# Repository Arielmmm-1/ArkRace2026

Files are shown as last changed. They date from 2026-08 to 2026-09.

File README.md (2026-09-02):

# Ark_Race2026


2026第五届方舟计划机器人大赛自述留档

## 废话
虽然这东西像破烂,但确实是我想出来的,但只停在想象,没考虑实际就直接做了,吸取教训吧🤫

## 目录结构
- 1.Embedded Team 电控组文件
- 2.Mechanical Group 机械组文件
- 3.培训‑机械组培训内容
- 4.Embedded Team\OLEDtest 整车电控文件，推荐 VSCode 打开
    - 其余为旧版本、临时文件、商家文件
- 5.Mechanical Group\我说元神牛逼你说队‑机械建模文件
    - 其余为26场地文件，参赛手册
      
## 📌 整车基础参数
- 参赛赛事：第五届方舟计划机器人大赛
- 整车重量：5.7kg（含遥控器）

---

## ⚙️ 一、硬件选型问题复盘
### 1. 驱动电机
- 核心问题：未计算整车负载扭矩，电机扭矩余量严重不足
- 实际表现：整车负重后速度疲软、动力不足
- 结构不匹配：该电机轴径小、原生不适配大直径车轮，重载工况非常吃力
- 迭代方案：后续可更换 24V 520 / 550 大扭矩电机，适配重载大轮场景


### 2. 法兰联轴器
- 现状：电机轴仅4mm，市面仅能匹配小型单面法兰联轴器
- 致命缺陷：大麦轮自重+惯性大，仅靠单颗六角螺母锁止完全不够
- 实战问题：全向平移时车轮微震、螺丝松动、运行极易掉轮


### 3. 主控板子（嘉立创天空星 F407VET6）
- 优点：F407芯片资源充足、主频、外设、内存完全满足比赛需求
- 事故问题：调试期间两次开发板烧毁
- 疑似原因：带电插拔、不断电操作导致瞬间电压冲击击穿
- 规范整改：后续所有接线、插拔、改装必须全程断电操作


---

## 🏗️ 二、底盘结构设计缺陷
### 1. 平板式底盘
- 结构短板：纯平面薄板底盘，不适合大尺寸、大重量车体
- 实际问题：整车5.7kg负重后底盘下沉形变，车轮倾角偏移
- 核心痛点：麦轮全向解算极度依赖结构刚性，形变误差软件完全无法补偿
- 经验总结：平板底盘仅适合小型轻量化小车，应该考虑采用铝型材框架的


### 附件可参考设计



---

## 📐 三、升降传送机构重大设计问题
### 1. 单边受力倾覆问题
- 结构硬伤：升降横梁左侧承载负载，产生巨大下压倾覆力矩
- 受力畸形：动力源集中在最右侧，受力点严重不对称
- 最后会出现光轴滑块卡顿、升降不顺、结构偏斜


### 2. 竖直立柱无闭环固定
- 设计漏洞：两根500mm高竖杆顶部无固定框架，未形成刚性矩形闭环
- 运动缺陷：车体一动，立柱整体高频抖动、振幅极大
(设计的时候以为横梁可以稳定这两根杆)

### 3. 步进电机固定方案简陋
- 现状：前期未预留标准安装孔位
- 临时方案：仅靠胶水+扎带固定，刚性极差、极易松动
- 改进：后续结构建模优先预留电机固定座、孔位
  
### 迭代优化思路
- 将传送驱动轴居中布置，右侧改为纯支撑光轴，弱化单边倾覆力
- 单根导向杆改为采用双滑块/四滑块到龙门架的结构，大幅提升承载稳定性


### 附件可参考设计



---

## 🤌 四、末端夹取机构总结
- 现状：舵机夹爪为赛前一晚才买的配件
- 优点：常规抓取表现尚可，适配比赛基础需求
- 缺陷：夹爪行程不足，无法包覆半个球体，抓取容错率低
- 后续升级方向：气动夹爪 / 磁吸抓取结构，稳定性、负载能力全面升级
  

### 附件


1f232b22a2a29387cc7f6337f348d309

---

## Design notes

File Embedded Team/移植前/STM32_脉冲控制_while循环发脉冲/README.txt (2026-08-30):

/**********************************************************
***	Emm_V5.0步进闭环控制例程
***	控制例程：STM32_脉冲控制_while循环发送脉冲
***	编写作者：ZHANGDATOU
***	技术支持：张大头闭环伺服
***	淘宝店铺：https://zhangdatou.taobao.com
***	CSDN博客：http s://blog.csdn.net/zhangdatou666
***	qq交流群：262438510
**********************************************************/

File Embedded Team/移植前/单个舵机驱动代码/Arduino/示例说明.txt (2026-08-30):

ResetServo	上电自动复位
Servo		循环让舵机从 0 度到 180 度，每隔 10 度转一次
MoreServo   多舵机控制

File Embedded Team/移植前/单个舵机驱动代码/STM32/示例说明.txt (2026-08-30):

01-Servo	上电自动复位
02-PulseServo	脉冲控制
03-AngleServo	通过角度控制

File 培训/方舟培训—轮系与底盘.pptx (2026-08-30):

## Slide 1

机器人常见轮系与底盘设计

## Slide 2

麦克纳姆轮

3

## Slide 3

麦轮结构

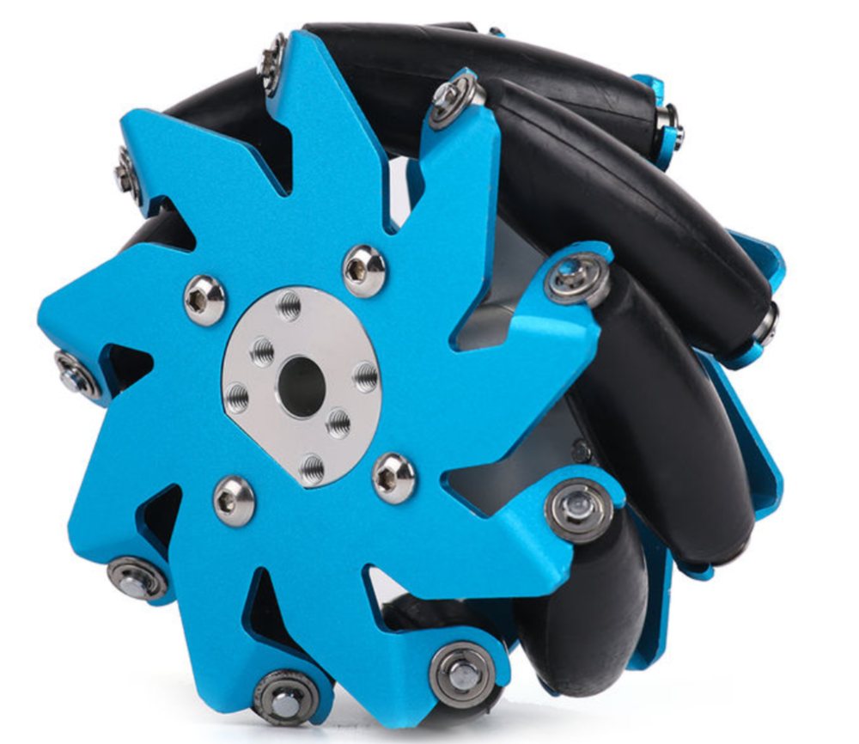
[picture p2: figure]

麦克纳姆轮由两大部分组成：轮毂和辊子（roller）
轮毂是整个轮子的主体支架
辊子则是安装在轮毂上的鼓状物。

轮毂轴与辊子转轴呈 45° 角

4

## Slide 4

麦轮运动方式

利用移动分解，实现平移、旋转等复杂动作

直线前进/后退

四个轮子转速相同、转向一致，机器人即可实现直线运动。

原地旋转

左右两侧的轮子组以相同转速、相反方向转动，机器人即可实现原地旋转。

横向平移

通过特定的轮子转速和转向组合，可以实现机器人在不改变朝向的情况下的横向移动。

斜向移动

控制各轮转速和转向不同，可实现机器人沿任意斜向的移动，运动轨迹灵活多变。

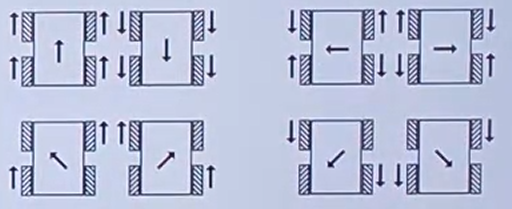
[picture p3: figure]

4

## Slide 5

麦轮的安装

麦轮一般是四个一组使用，两个A轮，两个B轮,或者会被称为左旋轮和右旋轮。A轮和B轮呈手性对称

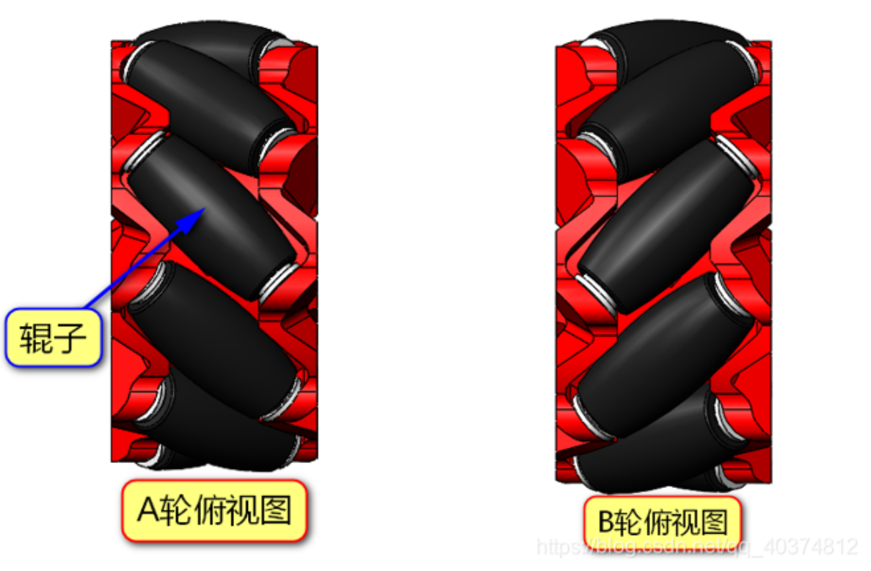
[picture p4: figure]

4

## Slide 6

麦轮的安装

X-正方形：轮子转动产生的力会经过同一个点，所以 yaw 轴无法主动旋转，也无法主动保持 yaw 轴的角度。一般几乎不会使用这种安装方式。
X-长方形：轮子转动可以产生 yaw 轴转动力矩，但转动力矩的力臂一般会比较短。这种安装方式也不多见。
O-正方形：四个轮子位于正方形的四个顶点，平移和旋转都没有任何问题。受限于机器人底盘的形状、尺寸等因素，这种安装方式虽然理想，但可遇而不可求。
O-长方形：轮子转动可以产生 yaw 轴转动力矩，而且转动力矩的力臂也比较长。是最常见的安装方式。

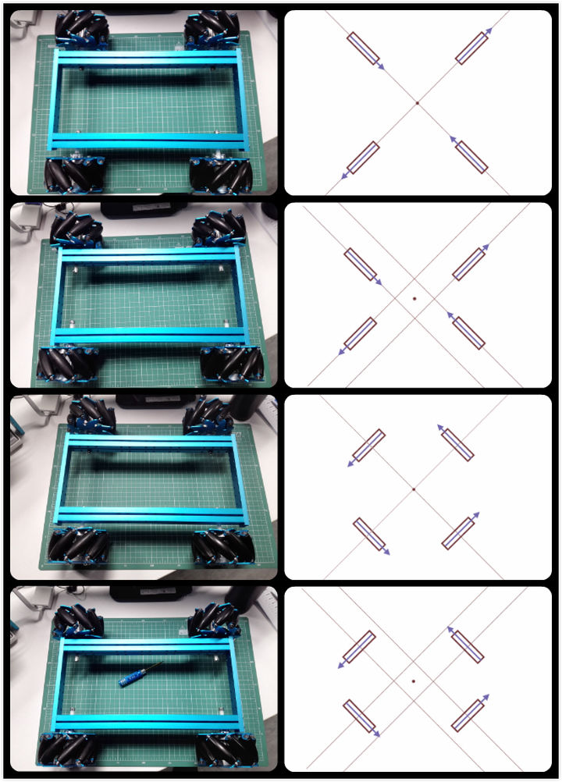
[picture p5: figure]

4

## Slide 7

全向轮

3

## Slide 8

全向轮结构

同样由轮毂和辊子构成，但轮毂轴与辊子转轴呈90度垂直。

全向轮一般是有两层的，但不是完全对称的，每层的辊子之间是存在较大间隙的，两层辊子恰好“插空”间隙，以保证全向轮滚动过程中，至少有一个辊子与地面接触。

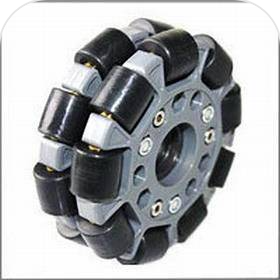
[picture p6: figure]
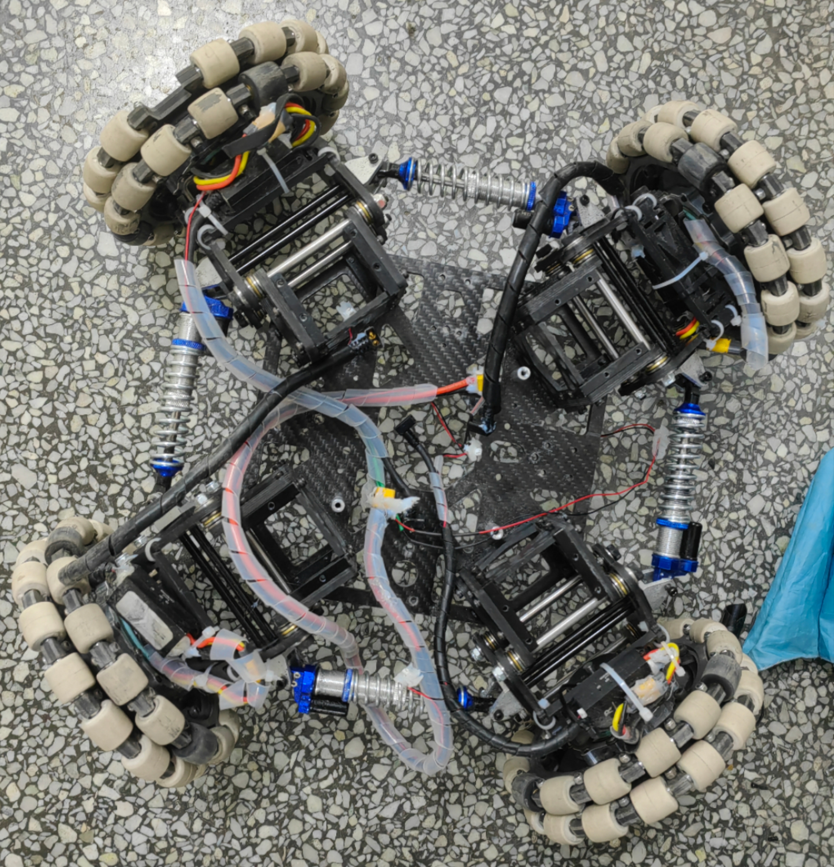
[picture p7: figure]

4

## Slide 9

全向轮安装结构

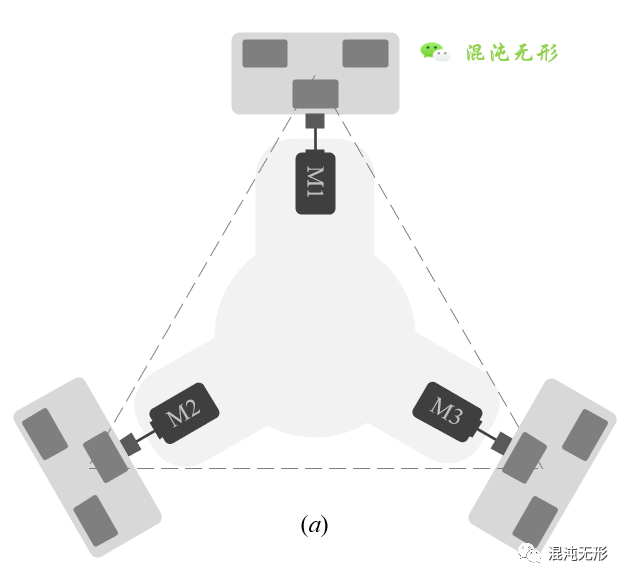
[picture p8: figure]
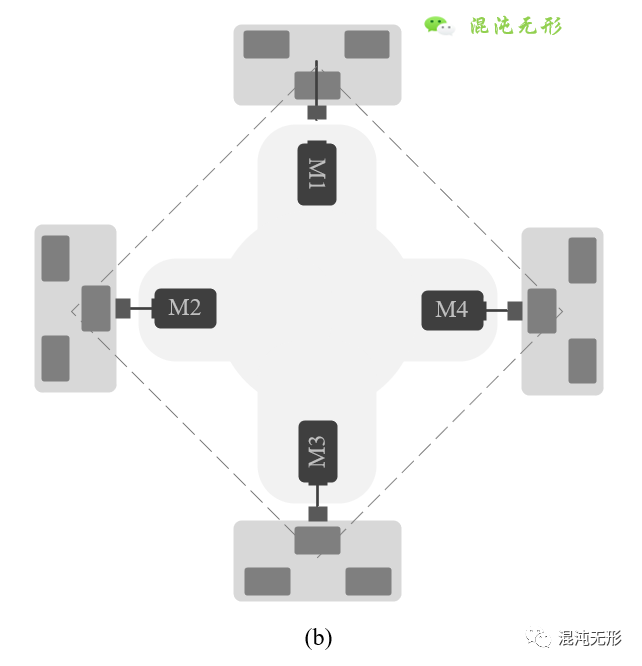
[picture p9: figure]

4

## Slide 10

舵轮

3

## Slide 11

舵轮

并非一种轮子，而是一种轮组机构．集成了驱动电机、转向电机、减速机等一体化的机械结构

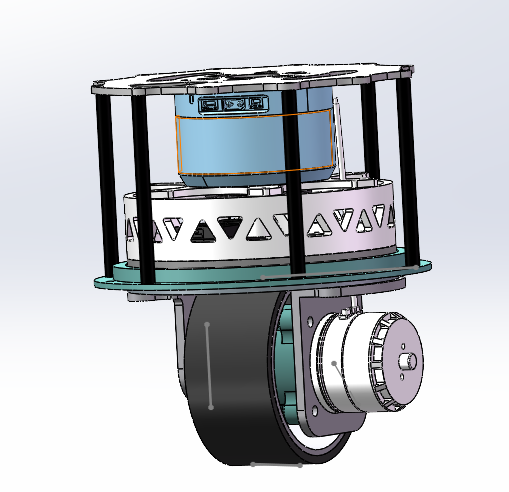
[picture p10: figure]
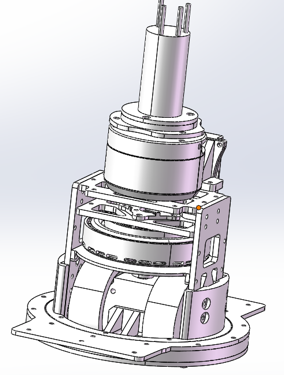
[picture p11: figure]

4

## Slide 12

对比与选型

3

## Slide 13

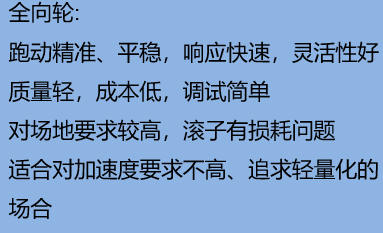
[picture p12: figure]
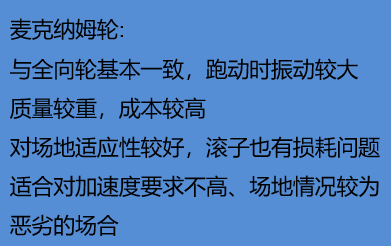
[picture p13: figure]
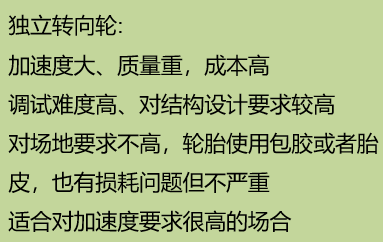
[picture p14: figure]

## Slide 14

底盘设计

3

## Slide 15

底盘设计

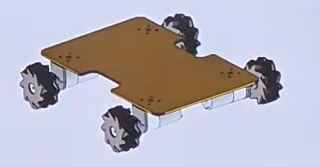
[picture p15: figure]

铝管主体底盘

板材主体底盘

仅适用于小型机器人，设计制作简单，强度随板子面积增大极速衰减

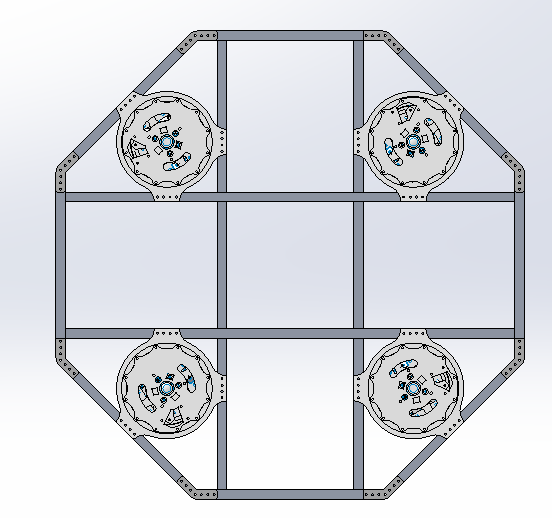
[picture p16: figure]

4

使用铝管作为底盘主体，结构紧凑，整体性较强，较为常用的底盘形式，强度与设计制作难度较为平衡，可根据机器人

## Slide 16

底盘设计

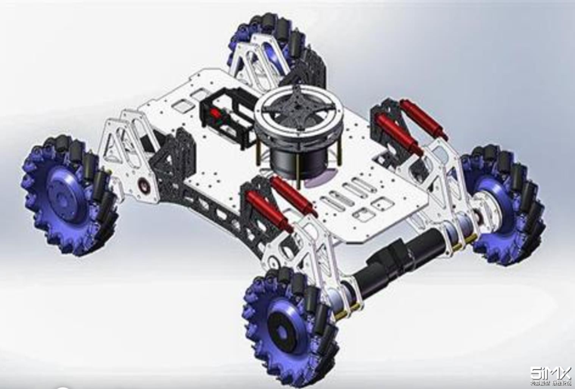
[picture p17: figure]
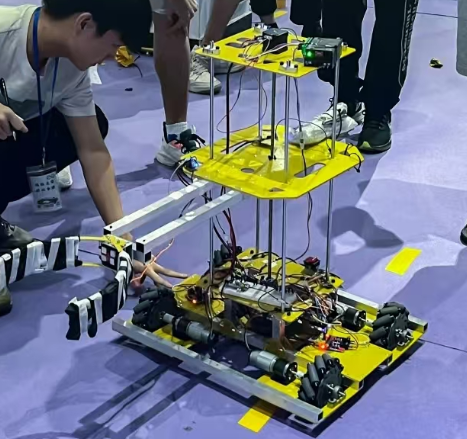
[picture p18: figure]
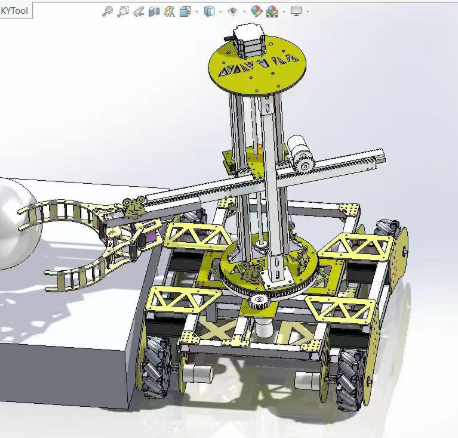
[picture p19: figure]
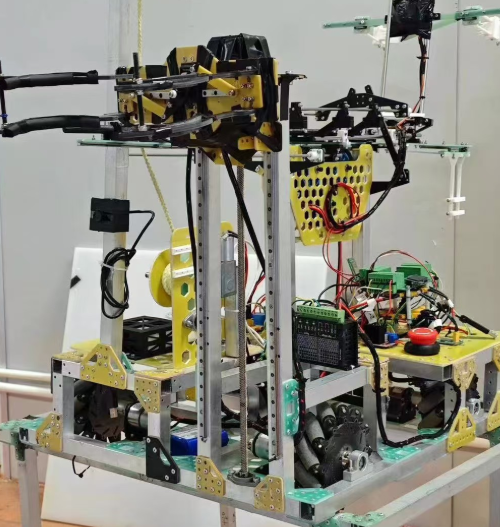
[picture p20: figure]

4

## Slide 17

谢谢观看

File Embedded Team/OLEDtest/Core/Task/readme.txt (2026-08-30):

/*----------------电机--------------*/
TIM8的 四通道PC6(CH1),7(CH2),8(CH3),9(CH4)PWM输出通道
1.电机1编码器:TIM3CH1=PB4、 CH2=PB5
2.电机2编码器:TIM4CH1=PD12、CH2=PD13
3.电机3编码器:TIM5CH1=PA0、CH2=PA1
4.电机4编码器:TIM1一CH1=PE9,CH2=PE11

TIM7做PID定时周期

TB6612-1
电机1-AIN1 = PD6, AIN2 = PD7
电机3-BIN1 = PB0, BIN2 = PB1

TB6612-2
电机2-AIN2 = PA4, AIN2 = PA6
电机4-BIN1 = PA5, BIN2 = PB6
/*--------------------------------*/

/*-------------------------------*/

步进电机
PD1(Stp)
PD2(Dir)

OLED
OLED_SCL- PB10
OLED_SDA- PB11

NRF24
CE → PB12
CSN → PB13
SCK → PB14
MOSI → PB15
MISO → PD9

夹爪舵机
PE5

附加测试：
裁判系统？

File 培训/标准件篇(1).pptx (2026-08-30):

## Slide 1

机器人入门培训

标准件篇

NAZARITE

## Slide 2

目录

I. 标准件的目的

II.实验室常用标准件

III.工具的使用

IV. 大工程师

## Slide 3

I.标准件的目的

NAZARITE

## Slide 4

1. 为什么要使用标准件？

首先我们要明白标准件是和谁相比“标准”？————和非标准件相比
标准件：标准件是指按照国家标准（GB）或者行业标准（欧标ISO）生产的，具有通用性和互换性的零部件。它们的特点是尺寸、形状、材料等方面都有明确的标准规定，可以在不同的产品中通用，因此具有较低的生产成本和较快的生产周期。
非标准件：非标件则是指那些不具备通用性和互换性的零部件，需要根据具体的产品设计或者生产工艺进行定制。它们的特点是尺寸、形状、材料等方面都有特殊的要求，无法在不同的产品中通用，因此生产成本较高，生产周期也较长。
标准件重要特点：便宜，通用，方便更换，用在特定场景

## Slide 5

2. 怎么找标准件？

1.大工程师/米思米：标准件很多且大多有图纸，但是只用于找型号，一般不在上面购买，淘宝会更便宜一些
个人经验
2.淘宝：质量参差不齐，可能有假货（轴承）
货比三家，同一个型号不同价格
不一定有图纸（可能是商家自己手测的，不保证精准）可以找商家要图纸，要不要得到是另外一回事
最好是要sw模型，如果只有图纸的话只能手绘，会比较费时
3.来实验室问师兄师姐，不懂就问

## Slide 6

Ⅱ.实验室常用标准件

NAZARITE

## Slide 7

1.紧固件

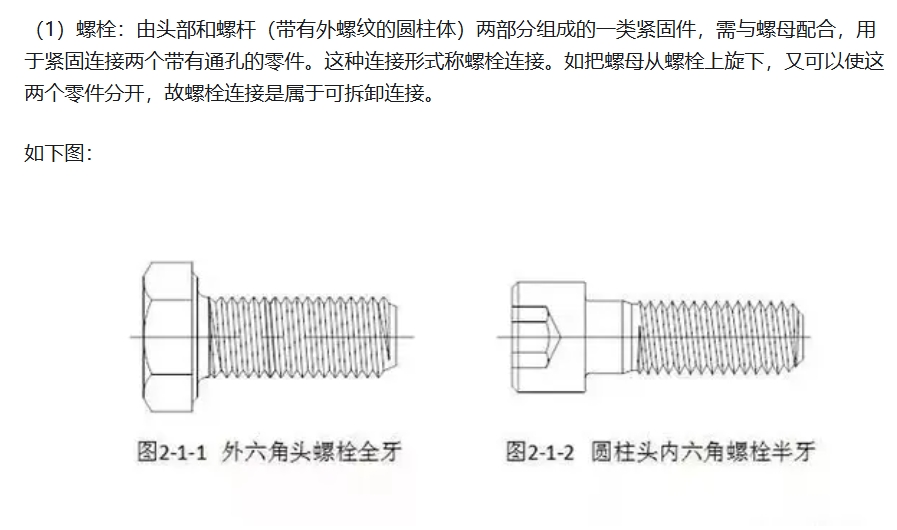
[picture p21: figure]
微信截图_20241024134753

用的最多的紧固件，常常和螺母一起使用，型号一般使用M3x长度
M代表三角螺纹，3代表公称直径，长度指去帽之后的长度
实验室常用的尺寸：M3/M4/M5
内六角：扭动时不易滑丝
平头：接触面积大
沉头：接触面积大 不会突出工件表面
圆头：圆

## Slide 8

1.1.紧固件种类：常用杯头/平头
内六角/十字槽

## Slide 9

1.2.紧固件规格

当我们要固定内六角螺丝时，
用的内六角扳手常常比螺丝小一圈，
这是因为内六角的尺寸不等于公称直径
d≠smax≠smin
建议大家来实验室的时候可以自己买一套内六角 商家都有配好的

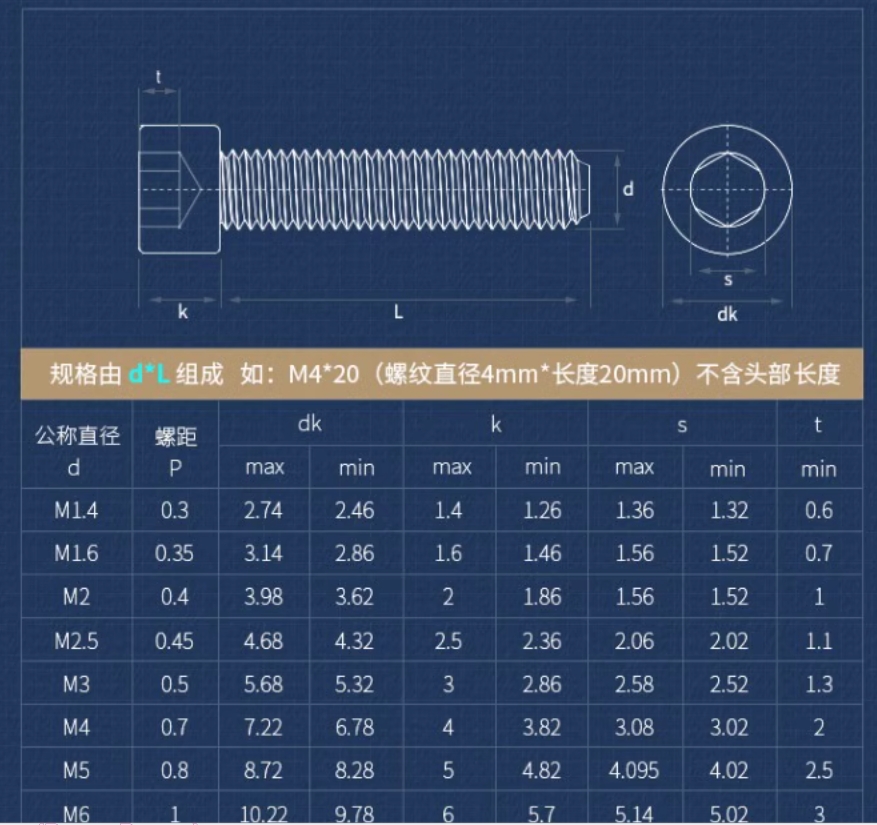
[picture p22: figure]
微信截图_20241024135416

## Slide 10

1.3:铆钉 自攻螺丝 丝锥

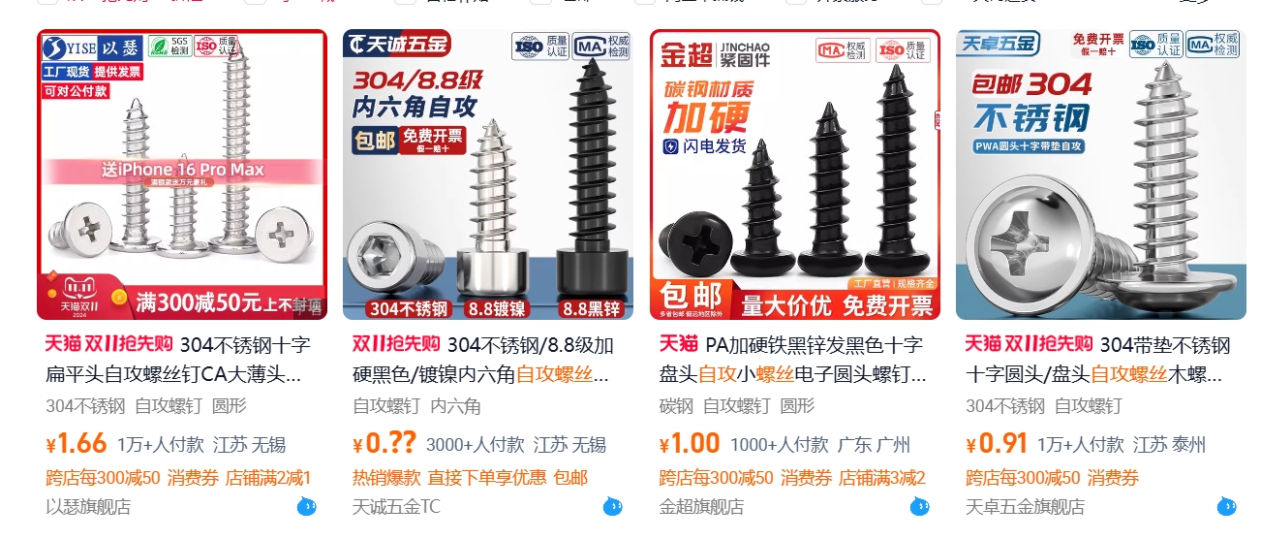
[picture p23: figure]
微信截图_20241024141800

不太常用，攻丝的时候会用到丝锥
当你的内六角被拧滑丝了，没有其他办法时，用丝锥在内六角内攻丝然后拧下来

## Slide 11

1.4.螺栓强度：

螺栓性能等级：钢结构连接用螺栓性能等级分为3.6、4.6、4.8、5.6、6.8、8.8、9.8、10.9、12.9等10余个等级，其中8.8级及以上螺栓材质为低碳合金钢或中碳钢并经热处理，通称为高强度螺栓，其余通称为普通螺栓。
计算公式：一般的螺栓是用"X.Y"表示强度的，X*100=此螺栓的抗拉强度，X*100*（Y/10）=此螺栓的屈服强度（因为按标识规定：屈服强度/抗拉强度=Y/10）。
如4.8级，则此螺栓的抗拉强度为：400MPa；屈服强度为：400*8/10=320MPa。
抗拉强度（tensile strength），物理学术语，是金属由均匀塑性形变向局部集中塑性变形过渡的临界值，也是金属在静拉伸条件下的最大承载能力，拉伸试样在承受最大拉应力之前，变形是均匀一致的，但超出之后，金属开始出现缩颈现象，即产生集中变形
屈服强度是金属材料发生屈服现象时的屈服极限，也就是抵抗微量塑性变形的应力。大于屈服强度的外力作用，将会使零件永久失效，无法恢复，小于这个的，零件还会恢复原来的样子。

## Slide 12

1.4.螺栓强度：

涉及材料力学的内容
稍微介绍一下
线性阶段
屈服阶段
硬化阶段
颈缩阶段

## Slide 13

1.5.注意事项：

在使用十字槽的紧固件时，使用对应的十字螺丝刀，不要图方便用小一号的，拧花牙了就没法拆下来了
内六角紧固件同理，请不要拧不动的时候强行加大电动螺丝刀扭矩
如果使用平头的螺丝，记得做倒角，使螺帽的表面沉入工件内（平头螺丝又叫沉头螺丝）
给对应的螺丝开孔时，留有一定公差，装配的时候不会因为孔开小了或者开大了导致紧固件失能
（具体请自己课下查表，涉及机械设计方面的问题，留到下节课继续讲）
如果不是最终确认设计的机构没问题且不需要拆卸，不要轻易使用铆钉，更不要使用钢制铆钉
实验室一般不需要攻丝，自攻螺丝也用的很少
在紧固件无法正常固定的情况下，可以试着给螺丝上胶水，简单粗暴

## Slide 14

2：螺母

常用：六角螺母，防松螺母，滚花螺母
防松螺母使用最多，使用时配合内六角扳手和尖嘴钳
（不是卡簧钳）
蝴蝶螺母一般不使用 只在一些需要经常松紧的场合使用，比如
台虎钳
滚花螺母一般用在打印件上，用电烙铁加热滚花螺母，由于是铜质的，所以滚花螺母会受热融化打印件，从而嵌进打印件内

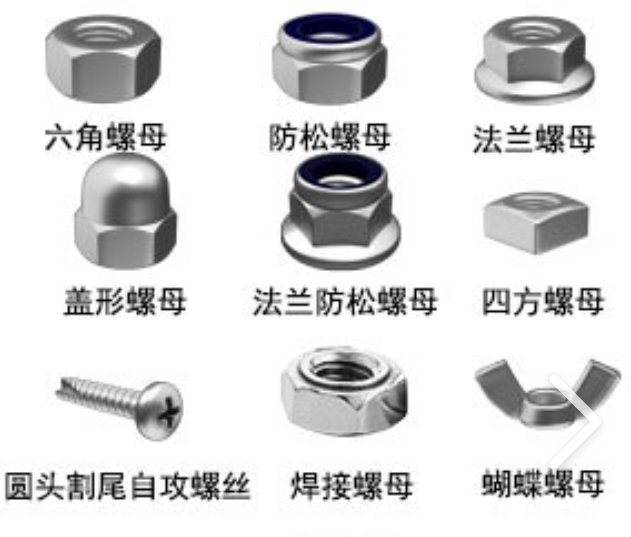
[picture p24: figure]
微信截图_20241024142856

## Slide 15

3：法兰 法兰联轴器 法兰轴承

法兰（Flange），又叫法兰凸缘盘或突缘。法兰是轴与轴之间相互连接的零件，用于管端之间的连接；也有用在设备进出口上的法兰，用于两个设备之间的连接

联轴器和轴承后面细说
可以理解成有着突缘的联轴器和轴承

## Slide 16

4：光轴

直线光轴是具有滑动轴承的引导作用，可使实行直线运动的产品。这些直线运动系统要求的必需条件是：
简单的设计，最好的执行能力，低价的维修费用，使用严格挑选坚固耐用的材料，高频热处理，准确的外径尺寸，真圆度，真直度及表面处理等。
常用于需要直线运动的机构 比如气缸活塞
或者提供转动 如“电机轴-联轴器-光轴-固定环-构件”组合
首先选择你需要的直径
一般要和法兰轴承的内径或者固定件的内径相同
直径越大越重，此时可以选空心光轴减少重量

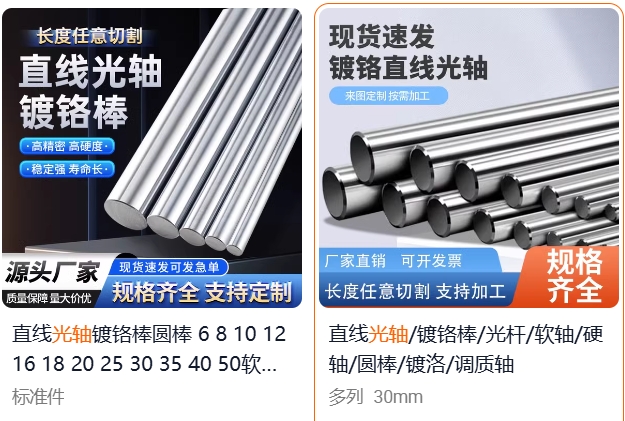
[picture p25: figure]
微信截图_20241024152443

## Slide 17

5：固定件

固定环：固定环可用于挡块、定位以及带轮的固定等普通用途，也可以用于轴承的内圈固定，通过开设各种安装孔也可以安装各种固定板等零件，孔的种类有通孔、螺孔、沉孔，同时也可以安装传感器或者用作缓冲器
通过拧紧顶丝来锁紧固定环，同样要注意不要滑丝
固定座：可以用于固定光轴 也可以用来固定丝杆
（需要额外安装锁紧螺帽）
种类很多，按情况选择

微信截图_20241024153224

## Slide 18

6：滑块滑轨

优点：精度高，摩擦力小，不易出现爬行现象，寿命长，静音
爬行现象：在机械学中指滑动摩擦副中从动件在匀速驱动和一定摩擦条件下产生的周期性时停时走或时慢时快的运动现象
缺点：滑块贵，特别贵，拆卸会掉钢珠，拆卸必须小心，十分小心！万分小心！！！
如何使用？将滑块和构件使用对应的螺丝锁紧，然后小心将滑块滑入滑轨内
有些特别精密的滑块会有注油孔，定时保养，实验室目前用不上
用的最多的是mgn7 mgn9

微信截图_20241024154955

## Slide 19

7：丝杆

https://zhuanlan.zhihu.com/p/116655775
普通丝杆满足螺纹升角小于当量摩擦角的条件时，可以自锁
一般要查表格
滚珠丝杆一般自锁不了，可以认为滚珠减小了接触面积

F= 2πηT/P
F：丝杆轴向驱动力（推力），N
T：电机输出扭矩，N・m
P：丝杆导程（转一圈移动距离），m
η：传动效率（滚珠丝杆 0.85~0.95；T型丝杆 0.25~0.5）

微信截图_20241024155457

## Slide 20

7.1：丝杆自锁公式

https://zhuanlan.zhihu.com/p/116655775
普通丝杆满足螺纹升角小于当量摩擦角的条件时，可以自锁
一般要查表格
滚珠丝杆一般自锁不了，可以认为滚珠减小了接触面积

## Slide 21

7.2：丝杆导程

微信图片_20241024171930

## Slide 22

8.联轴器

一般有这四种联轴器
中心补偿能力：
绕线＞膜片＞刚性
不推荐使用梅花联轴器
非常容易坏
绕线联轴器只能一定程度上减轻两个轴不对心的问题 不能完全解决（强行对齐是一定会严重变形的）
联轴器是指联接两轴或轴与回转件，在传递运动和动力过程中一同回转，在正常情况下不脱开的一种装置。有时也作为一种安全装置用来防止被联接机件承受过大的载荷，起到过载保护的作用。

微信截图_20241024165705
微信截图_20241024165948

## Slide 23

8.1.联轴器注意事项

1.所需传递转矩的大小和性质
2.由制造和装配误差、轴受载和热膨胀变形以及部件之间的相对运动等引起两轴轴线的相对位移程度
3.为了便于装配、调整和维修所必需的操作空间
日常保养：
检查是否变形 有裂纹 检查顶丝是否紧固

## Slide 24

9.轴承

轴承的种类繁多，在这里只是简单的介绍几种，在轴系设计课程中会详细的介绍，这里只讲三种实验室最常用的轴承
1.深沟球/滚子/滚针轴承
2.推力球/滚子/滚针轴承
3.角接触球轴承
4.法兰轴承

微信截图_20241024200042
微信截图_20241024200010
微信截图_20241024201517

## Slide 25

9.1轴承

所有的轴承都是由四部分组成：内圈 外圈
滚动体 保持架
其中文章最多的是：滚动体，可以分为三类
滚珠/滚子/滚针
滚珠：球
滚子：圆柱体
滚针：特别细长的圆柱体
当滚子直径D≤5mm，L/D≥2.5时，就叫滚针，
L为滚子长度
角接触轴承在内外圈，改变了与滚动体的角度 一般是15° 30° 45°
另外：轴承型号后面可能带有Z/F/ZZ/RS等代号
Z：代表单面防尘盖
ZZ：代表双面防尘盖 RS：双面密封圈
F：法兰轴承

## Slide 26

9.2各轴承特点

深沟球轴承：
实验室最常见用的也最多的轴承
主要承受径向载荷 能承受一定的轴向载荷 但设计上一般不用来承受轴向载荷
轴向：顺着轴的方向
径向：垂直于轴的方向
选型时一般看内外径和厚度
合适就好 有精度要求的需要自己查公差表，这里不赘述
也有滚子/滚针轴承

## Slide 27

9.2各轴承特点

推力球轴承：
最容易爆装备的轴承，未固定时会分成三片，妥善保管
只能承受轴向力，不能承受径向力，会滑脱
选型时一般看内外径和厚度
滚动体可以分为滚珠和滚子，常用滚珠，也有滚子和滚针的

微信截图_20241024210517

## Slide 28

9.2各轴承特点

法兰轴承
可以理解成有法兰形状的
深沟球轴承
最大特点是将法兰与轴承结为一体。当轴的一端没有连接件，需要固定在平面如板、墙壁上时，法兰轴承就体现出其优势。
选型时一般看内外径和厚度
主要是为了定位轴，常见结构：法兰轴承-光轴-
固定环-机构-联轴器-法兰轴承-电机

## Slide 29

NAZATITE

法兰

型号查询：http (http://s.sozhou.com/)://s.sozhou.com/

深沟

图片包含 图示 AI 生成的内容可能不正确。

推力

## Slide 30

9.2各轴承特点

角接触轴承：
不常见，难装配，但是有些地方角接触轴承特别适合
径向载荷 轴向载荷 都能承受 这是因为它的结构比其他的轴承特殊一些
https://www.bilibili.com/video/BV1PR4y187xJ/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
一般成对安装
面对面
背对背
面对背

找不到很明显清楚的图，看视频吧
https://www.bilibili.com/video/BV1hu411t7vf/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

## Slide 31

10.涨紧套

胀紧联结套（简称胀套），是当今国际上广泛用于重型载荷下机械联结的一种先进基础部件，在轮和轴的联结中，它是靠拧紧高强度螺栓使包容面间产生的压力和摩擦力实现负载传送的一种无键联结装置。

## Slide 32

11.角码

角码是连接90度直角相交构件的五金件，一般用螺栓固定
常用于铝合金结构上的固定，比如铝型材，铝管
也有其他角度的角码，比如30°，45°

微信截图_20241024211804
微信截图_20241024211814

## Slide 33

12.铝型材 铝管

铝管：实验室最常用，规格10mmx10mm/20mmx20mm
通过在铝管上钻孔，与紧固件进行固定（如螺栓螺母，铆钉）
便宜好用 一代车基本都用铝管做框架
雕刻机可以钻铝孔，也可以用手电钻开孔（比较吃个人的手稳程度）
铝型材：实验室不太常用，规格20mmx20mm（2020），30mmx30mm（3030），还会细分牌号系列啥的
一般会配合铰链转动，用滑块螺母和角码来固定
比较重，所以实验室不常用

微信截图_20241024213218

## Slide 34

III.工具的使用

NAZARITE

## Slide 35

常见工具

微信截图_20241024213904
微信截图_20241024214058

不要乱用
每个工具都有自己的功能
别贪方便就直接拿卡簧钳当
尖嘴钳用，会断掉

建议自己一人买一套内六角和钳子不需要太贵的 都行
自己保管
自己使用

微信截图_20241024213730
微信截图_20241024213935
微信截图_20241024215037

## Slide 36

NAZATITE

谢谢观看！

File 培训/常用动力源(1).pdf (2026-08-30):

欲戴王冠 必承其重


[作者姓名] 1

机械组技术文档——常用动力源

## 常用动力源

工业上常用的驱动方式有气动、电动以及液压驱动，在队里我们一般使用气

动与电动驱动方式。

## 一、气动

气动，顾名思义就是利用压缩空气，带动机械结构完成伸缩或者旋转动作。

整个气动结构由气源、气路和气缸三部分组成。当机构某一部分需要的状态有且

仅有两种时，可以考虑使用气动。气动的优点在于控制较为方便，可以提供较大

的力/扭矩，缺点在于气缸工作时会带来震动、可以实现的状态单一、需要额外

添加气瓶且在精度上不如电机控制。

1.1 气源

气源是压缩空气的存储装置，一般指空压机或者事先充好气的气瓶


队里常用的气压为 0.6Mpa(6 个大气压)，气压低于 0.4Mpa 时需要进行充气，

气瓶由可乐瓶(迟到带的饮料)制成，具有良好的耐压性与轻便性。空压机是队里

一切压缩空气的生产者，有且仅有一台，需要爱护(虽然它很吵)。

1.2 气路

气路由气管、转接头、气阀组成。

气管队里有两种，一种是队内最常使用的普通 PU 气管，直径(外径)有 6mm、

4mm 两种，可以满足大部分情况下的要求；另一种是螺旋式气管，这类气管的好

处在于有极大的伸缩性，但由于普通气管已经能够满足我们的使用要求，所以这

类气管在队里较少使用。


[作者姓名] 2


队里常见的转接头有十字转接头、三通对接头、快速接头(4 转 4、4 转 6、6

转 6)等等，用于拓展气路或者适配气缸。


气阀这里需要着重介绍，队里常见的气阀有气路开关、限流阀、单向阀以及

电磁阀。

气路开关如图所示，通过转动上方的旋钮来控制气路的

开闭。图中气路开关的状态为打开。

限流阀如图所示，转动旋钮可以控制气路中气流的速度，

进而调节气缸运动的快慢。

单向阀如图所示，还有一种单向阀与气路开关外形一致，但

是有图中方框内的标识，需要注意区分。图中的单向阀允许的气

体流动方向为从上至下。

电磁阀如图所示，电磁阀内部是通过电磁铁吸引阀芯，改变阀芯的位置进

而改变气路流通的方向，队里常用的有 3 位 5 通、2 位 3 通电磁阀，(“位”指

状态，“通”可以理解为能够连接的气管数)有关电磁阀的讲解详见课件部分。


[作者姓名] 3


需要注意的是，电磁阀并非只能通过电控来控制，图中蓝色的小按钮可视为

电磁阀的机械开关，在通气状态下，用钉子或者螺丝刀持续按下蓝色小按钮也可

以触发电磁阀，这种触发方式多用于机构实验简化控制流程时用。

1.3 气缸


气缸是气路的末端执行部件，市面上的气缸种类五花八门，大致可以分为直

动式和旋转式两种。我们关注的气缸性能参数大致有两个，一个是气缸的行程(长

度/角度)，另一个是气缸可以提供的力/扭矩(由缸径决定)。

1.直动式气缸

队里常用的直动式气缸是 CDJ2B 式气缸，通过气缸杆

的伸缩来驱动机构，这类气缸的用途最为广泛，适用执行

机构直动的场合，气缸杆的输出可以视为恒定的力(气压不

变的情况下)。


2.旋转式气缸


[作者姓名] 4

队里常用的旋转气缸为 CRB2B 式气缸，通过气缸轴的旋转

来带动机构旋转，由于气缸轴上没有特别的孔位用于连接，所

以队里一般配合固定环使用，又因为固定环不宜在冲击较大

的场合使用，因此使用 CRB2B 旋转气缸的机构一般不是很可

靠，多次触发后固定环和气缸轴之间易发生松脱。

3.其他气缸

除了上面介绍的两种普通的气缸外，市面上还有各种各样的气缸，如旋转下

压气缸、手指气缸、滑台气缸、无杆气缸等等，这里我们介绍一下旋转下压气缸

和手指气缸。

旋转下压式气缸可以理解为旋转气缸的气缸轴上有非自锁的螺纹副配合，因

此当气缸轴伸缩时还会随着螺纹旋转。根据内部螺纹旋向的区别可分为左旋下压

式和右旋下压式。


手指气缸如图所示，可分为平动式与旋转式，使用场合较为特殊，在 21 年武

大冠军车上有着很好的应用。


气动的核心部分在于气缸，由于气缸对于气密性有着严格的要求，所以气缸

杆/轴不应长时间受力，尤其是不能受侧向力，不然会大大减少气缸的使用寿命


[作者姓名] 5

甚至直接报废(轴用型气缸(缸径很大的气缸)例外)。对于 CDJ2B 型气缸，要保证

气缸杆光滑，拧气缸头螺母时禁止用斜口钳夹住气缸杆，不然气缸伸缩时会在夹

痕处卡住，导致气缸报废。在设计含有气缸的机构时，应把气缸视为触发装置，

而非提高系统刚度以及用来导向的装置。

## 二、电动

电动驱动是以电机为核心的驱动方式，包括电机、驱动器、减速器、执行

装置。

电动驱动较气动驱动的优点在于可以实现无极控制、可编程、可以实现速

度、位置、力/扭矩的较精确控制、占用的空间较小等等。缺点在于控制较为复

杂，出现问题较难排查，使用不当易造成元器件损坏等等。

2.1 电机

电机可以大致分为有刷电机和无刷电机，电机的基本原理即通电导体在磁

场中会受到安培力。电机内部由定子和转子构成，对于有刷电机，有刷电机的

定子为永磁体，转子为线圈，是通过电刷和线圈运动的惯性来改变电机线圈内

直流电流动方向，进而

无刷电机是队里使用最广泛的电机，与有刷电机不同的是，无刷电机的转

子是永磁体，定子是线圈，。对于无刷电机，根据封装与否可以分为封装式电机

和直驱式电机，封装式电机一般自带减速箱，例如大疆的 M2006、M3508 电机，

还有 T-motor AK 系列的关节电机，这几款电机除了自带减速箱，也对编码器和

驱动器进行了封装。

直驱式电机一般是航模电机，没有自带的减速器，也没有封装好的编码器

驱动器，例如 T-motor 的 U10、U8 电机，双天的 4255、5060 电机、SUNNYSKY

的 4006、3506 电机等等，使用这类电机需要我们自己安装编码器、驱动器以及

小磁铁。


[作者姓名] 6

除了电机的尺寸大小、孔位之外，我们在意的电机参数有极对数、KV 值、

功率、最大电流、持续电流、最大扭矩、持续扭矩、最大转速等等，这些参数

在官网上或者电机手册上一般可以查到，但是这些参数仅供参考，并不代表电

机的实际性能，尤其是队里买新电机之后一定要找控制组同学测一下电机的参

数。

这里介绍一下电机的极对数和 KV 值。

供给无刷电机的电流为三相电；电机的 KV 值表示电压每增加 1V，空载下电

机增加的转速(rpm)，一般电机的 KV 值越小，电机的扭矩越大，电机的极限转

速越小。

电机的极对数

我们常浏览的电机网站有：

上海双天模型有限公司 (dualsky.com) (http://cn.dualsky.com/)

T-motor-更安全的动力系统 (tmotor.com) (https://uav-cn.tmotor.com/)

DJI 大疆商城 - DJI 大疆无人机、手持稳定器、专业影像设备及增值服务 (中国大陆) (https://store.dji.com/cn)

SUNNYSKY-更稳定的动力系统 (rcsunnysky.com)

江西迈得机电 – 专业无人机无刷电机设计及生产厂家 (madmotor.cn)

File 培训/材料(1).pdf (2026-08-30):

材料

铝材

：


## 复合木板：

三合板木板复合板手工模型材料多层胶合板薄板片隔板尺寸定制定做-淘宝网 (https://item.taobao.com/item.htm?detail_redpacket_pop=true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)
复合木板（Engineered Wood）是一类以木材为原料，通过加工重组和胶合工艺 制成的人造板材。与天然实木相比，复合木板通过结构优化解决了木材易变形、 尺寸受限等问题，同时提高了资源利用率，广泛应用于家具、建筑和装饰领域。


## 环氧绝缘板：

进口 FR4 环氧树脂 3240 绝缘板 G10 玻纤棒玻璃钢板阻燃玻璃纤维板加工-淘宝网 (https://item.taobao.com/item.htm?id=608568469892)
环氧绝缘板（Epoxy insulation board）是一种以环氧树脂为基体、玻璃纤 维布为增强材料，通过高温高压层压工艺制成的复合绝缘材料。它兼具高分子材 料的绝缘性和玻璃纤维的机械强度，是电子电气领域最常用的高性能绝缘材料之 一。


## 玻璃纤维板：

玻璃纤维板（Glass Fiber Reinforced Polymer，简称 GFRP 或玻璃钢）是 一种以玻璃纤维为增强材料、合成树脂为基体，通过层压、模压或拉挤等工艺制 成的复合材料。它结合了玻璃纤维的高强度和树脂的耐腐蚀性，广泛应用于电子 电气、建筑、交通等领域。应用非常广泛。具有吸音，隔声，隔热，环保，阻燃 等特点。


## 碳纤维板材：


碳板（Carbon Fiber Reinforced Polymer，简称 CFRP 或碳纤维板）是一种 以碳纤维为增强材料、树脂为基体的高性能复合材料，通过高温高压工艺成型。 其以极高的强度重量比、优异的耐疲劳性和可设计性，广泛应用于航空航天、汽 车制造、体育器材等高精尖领域。

问：“哪种板材更好？为什么？”
Tips：“弹性模量”的一般定义是：单向应力状态下应力除以该方向的应变。 (https://baike.baidu.com/item/%E5%BA%94%E5%8A%9B%E7%8A%B6%E6%80%81/7741054?fromModule=lemma_inlink)

## 抗拉强度：

一般是指塑料或金属等由均匀塑性变形向局部集中塑性变形过渡的临界值， 也是塑料或金属在静拉伸条件下的最大承载能力。它表示材料在拉力作用下抵抗


破坏的最大能力。拉伸试样在承受最大拉应力之前，变形是均匀一致的，但超出 之后，金属开始出现缩颈现象。对于没有(或很小)均匀塑性变形的脆性材料，它 反映了材料的断裂抗力。
【拉伸实验，缩颈现象，q235 试样】 拉伸实验，缩颈现象，q235 试样_哔 哩哔哩_bilibili (https://www.bilibili.com/video/BV1WJ411978Z/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)

## 屈服强度：

屈服强度指材料在出现屈服现象时所能承受的最大应力。当应力超过弹性极 限后，变形增加较快，此时除了产生弹性变形外，还产生部分塑性变形，造成两 种形变的的临界点的强度，就是材料的屈服强度。
无弹性的材料没有屈服强度。如各类金属材料、塑料、橡胶等等，都有弹性， 都有屈服强,但玻璃、陶瓷、砖石等等，一般没有弹性,这类材料就算有弹性，也 微乎其微，所以没有屈服强度一说。
屈服强度是金属材料发生屈服现象时的屈服极限，也就是抵抗微量塑性变形 的应力，

Tips：屈服现象是在材料受到外力作用时，当应力达到一定值后，即使应力 不再增加或仅在小范围内波动，材料的变形却会急剧增长的现象

### 材料的力学性能：

### 一、 强度

金属材料在外力作用下抵抗塑性变形和断裂的能力，或材料抵抗破坏的能力。 按外力作用的性质不同，强度主要有屈服强度、 (https://zhida.zhihu.com/search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)抗拉强度、 (https://zhida.zhihu.com/search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)抗压强度、 (https://zhida.zhihu.com/search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)抗弯强度 (https://zhida.zhihu.com/search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) 等，工程常用的是屈服强度和抗拉强度，这两个强度指标可通过拉伸试验测出， (https://zhida.zhihu.com/search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) 其单位为 Pa。

### 二、 硬度

硬度指“固体材料抗拒永久形变的特性”。材料局部抵抗硬物压入其表面的 能力称为硬度。固体对外界物体入侵的局部抵抗能力，是比较各种材料软硬的指 标。一般硬度越高，耐磨性越好。

### 三、 刚度

刚度是指零件在载荷作用下抵抗弹性变形的能力。零件的刚度（或称刚性） 常用单位变形所需的了或力矩来表示，刚度的大小取决于零件的几何形状和材料 种类（即材料的弹性模量）。刚度要求对于某些弹性变形量超过一定数值后，会 影响机器工作质量的零件尤为重要，如机床的主轴、导轨、丝杠等。

刚度、强度和硬度的区别:

1.强度:金属材料在外力作用下抵抗塑性变形和断裂的能力。 2.硬度:金属材料抵抗更硬的物体压入其内的能力。
3.刚度:金属材料在受力时抵抗弹性变形的能力。

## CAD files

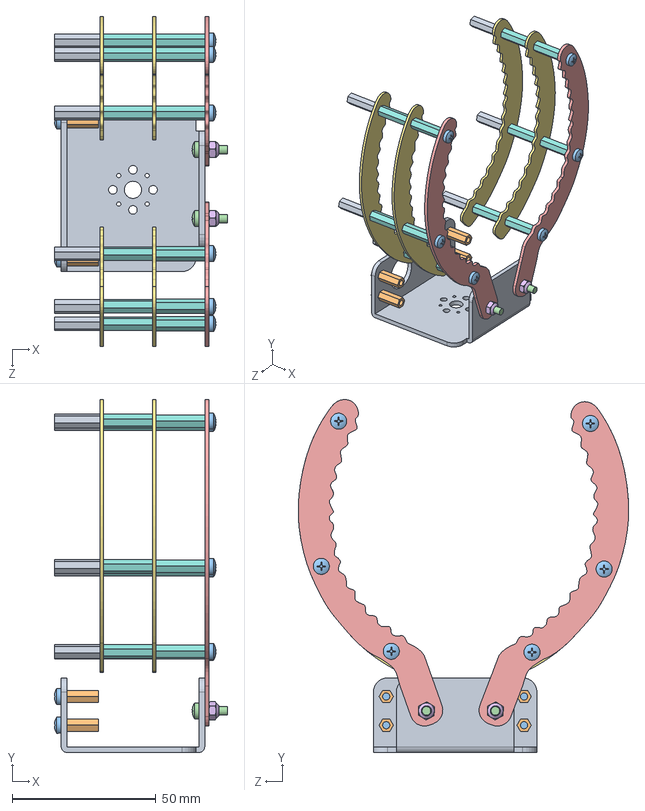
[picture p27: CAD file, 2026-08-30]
Mechanical Group/我说元神牛逼你说队/抓取/版本2/sw/装配体6.SLDASM
60.4 x 122.9 x 115.1 mm
支架1
M3X11双通铜柱 x 4
GB818-M3X6-ZN-4.8 x 10
GB818-M3X10-ZN-4.8 x 2
底部长支架 x 2
GB6170-M3（自锁） x 2
短支架 x 4
M3X17+6铜柱 x 12
M3X16双通铜柱 x 6

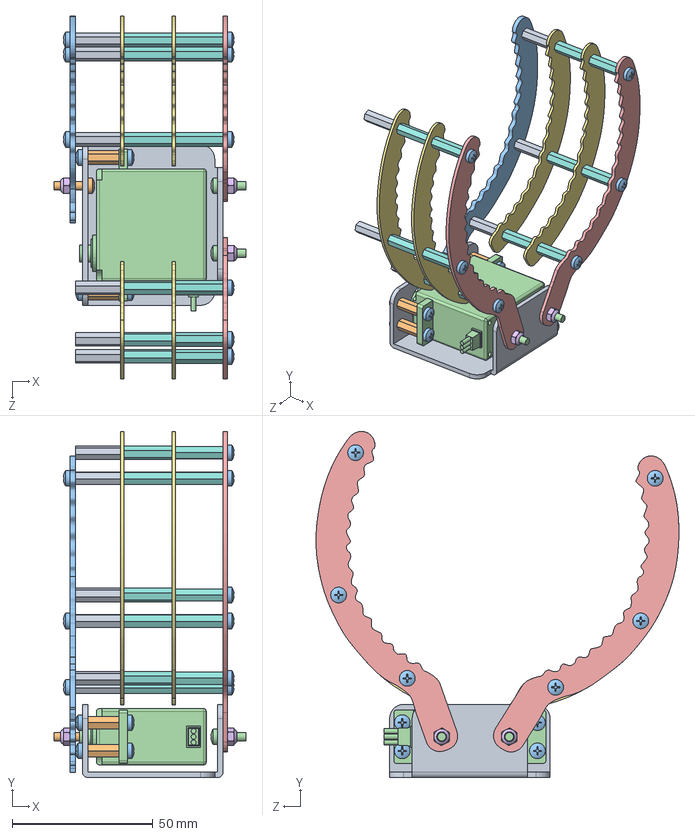
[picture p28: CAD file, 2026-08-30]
Mechanical Group/我说元神牛逼你说队/抓取/版本2/sw/装配体8.SLDASM
68.0 x 122.9 x 128.9 mm
支架1
M3X11双通铜柱 x 4
GB818-M3X6-ZN-4.8 x 17
GB818-M3X10-ZN-4.8 x 2
底部长支架 x 2
GB6170-M3（自锁） x 3
短支架 x 4
M3X17+6铜柱 x 12
M3X16双通铜柱 x 6
GB818-M3X12-ZN-4.8
左边长支架
小舵机

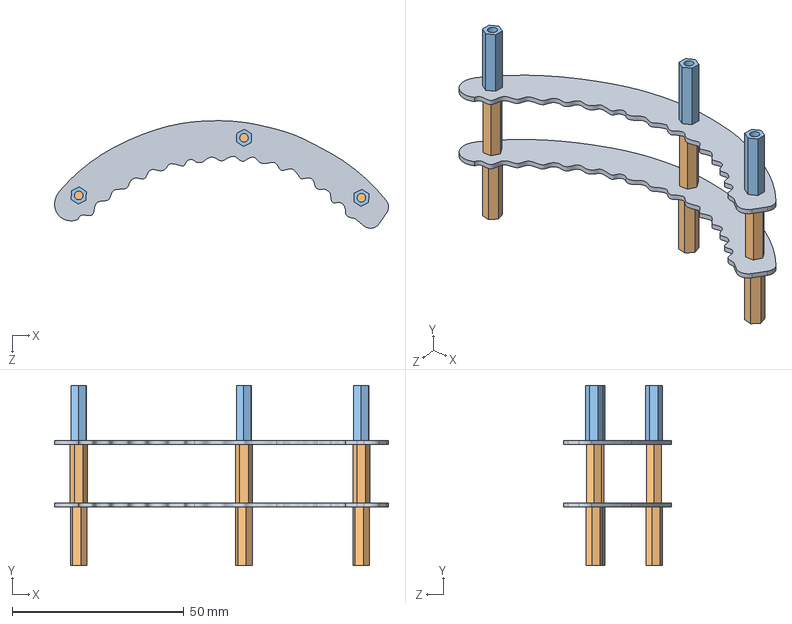
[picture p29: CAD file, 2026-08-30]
Mechanical Group/我说元神牛逼你说队/抓取/版本2/sw/装配体3.SLDASM
97.1 x 52.4 x 31.3 mm
短支架 x 2
M3X17+6铜柱 x 6
M3X16双通铜柱 x 3

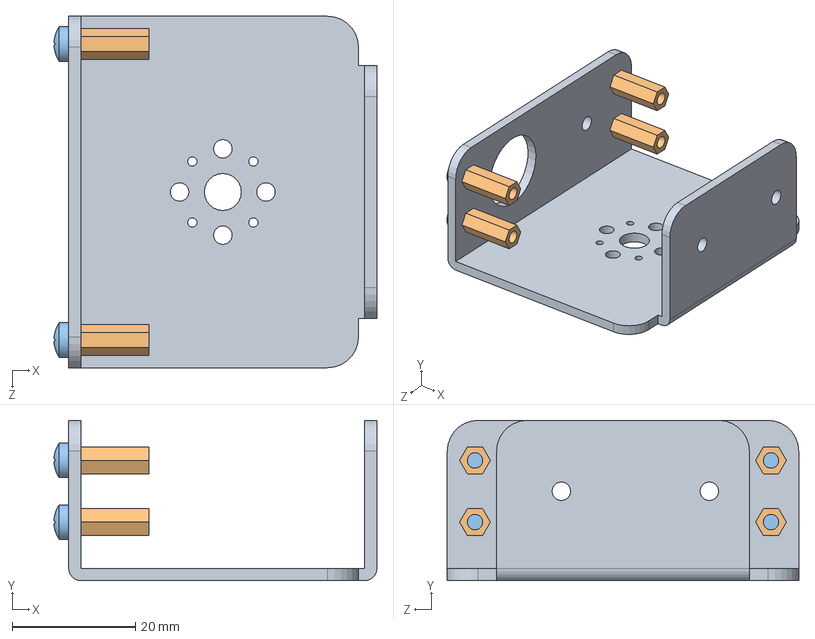
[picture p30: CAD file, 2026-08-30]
Mechanical Group/我说元神牛逼你说队/抓取/版本2/sw/装配体1.SLDASM
52.4 x 26.0 x 57.0 mm
支架1
M3X11双通铜柱 x 4
GB818-M3X6-ZN-4.8 x 4

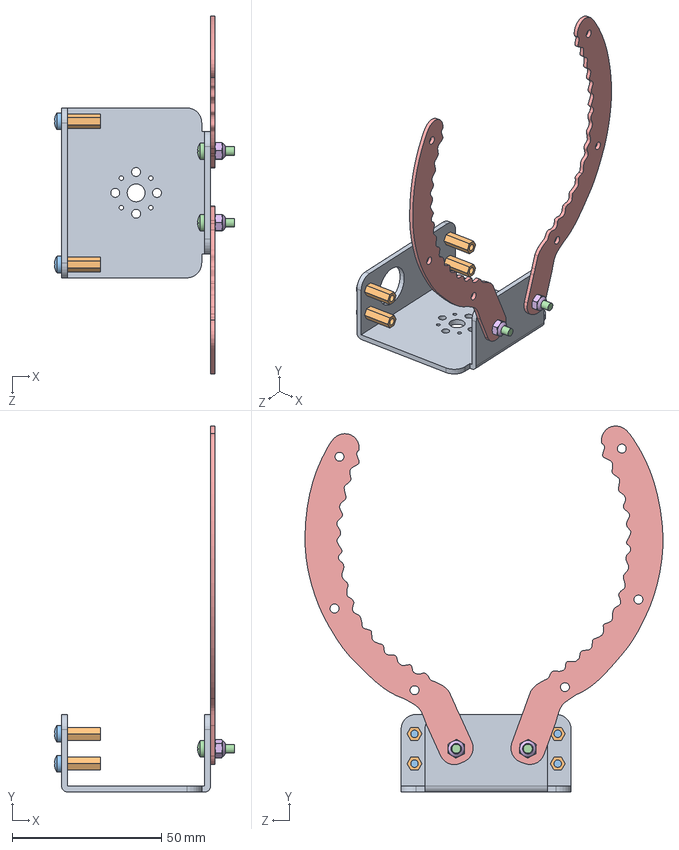
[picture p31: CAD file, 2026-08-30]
Mechanical Group/我说元神牛逼你说队/抓取/版本2/sw/装配体2.SLDASM
60.4 x 122.6 x 119.9 mm
支架1
M3X11双通铜柱 x 4
GB818-M3X6-ZN-4.8 x 4
GB818-M3X10-ZN-4.8 x 2
底部长支架 x 2
GB6170-M3（自锁） x 2

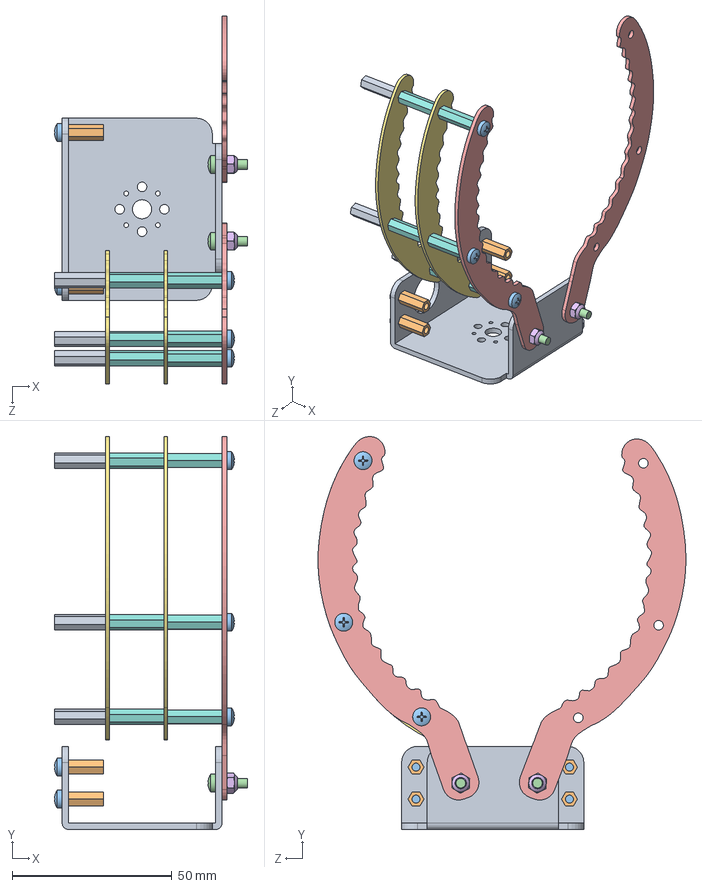
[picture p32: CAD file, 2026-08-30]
Mechanical Group/我说元神牛逼你说队/抓取/版本2/sw/装配体5.SLDASM
60.4 x 122.9 x 115.1 mm
支架1
M3X11双通铜柱 x 4
GB818-M3X6-ZN-4.8 x 7
GB818-M3X10-ZN-4.8 x 2
底部长支架 x 2
GB6170-M3（自锁） x 2
短支架 x 2
M3X17+6铜柱 x 6
M3X16双通铜柱 x 3

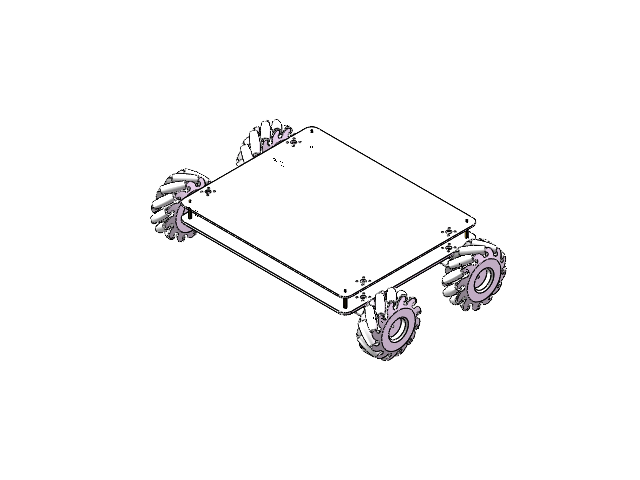
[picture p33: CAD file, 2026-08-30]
Mechanical Group/我说元神牛逼你说队/底盘/小车底盘.SLDASM
JGA25-371电机 x 4
电机固定 x 4
100mm麦克纳姆轮右旋轮 x 2
联轴器 x 4
100mm麦克纳姆轮左旋轮 x 2
各尺寸公母铜柱 x 4
底板上
底板下

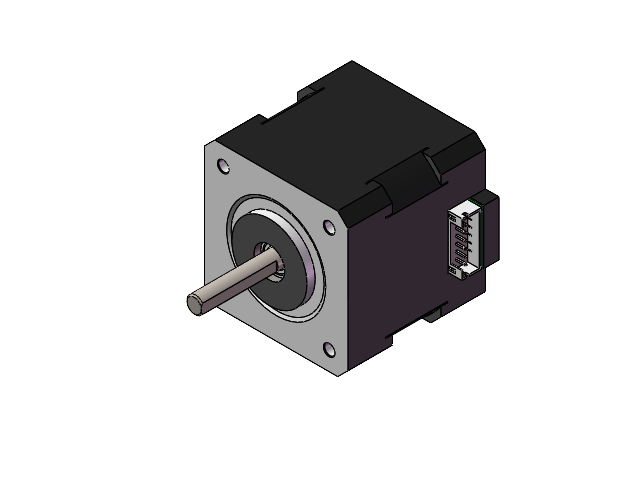
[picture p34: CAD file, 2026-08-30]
Mechanical Group/我说元神牛逼你说队/升降结构/杂/42 step motor-38mm.SLDASM.SLDASM
42_____________22mm

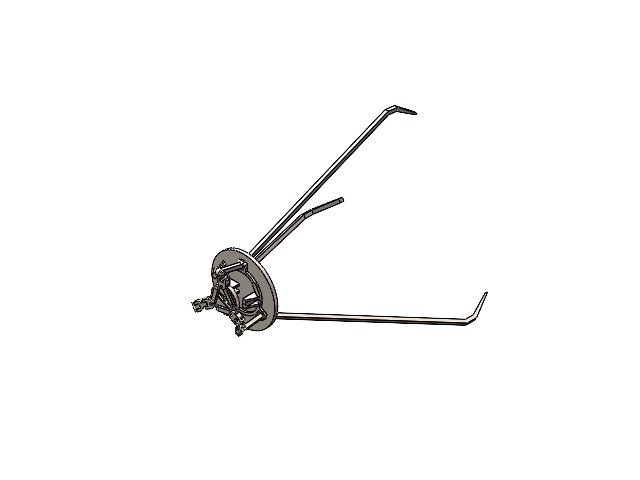
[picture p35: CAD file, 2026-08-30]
Mechanical Group/我说元神牛逼你说队/抓取/版本1/sg90夹爪.SLDASM
基座
爪 x 3
舵盘
拉杆1 x 3
拉杆2 x 3
拉杆3 x 3

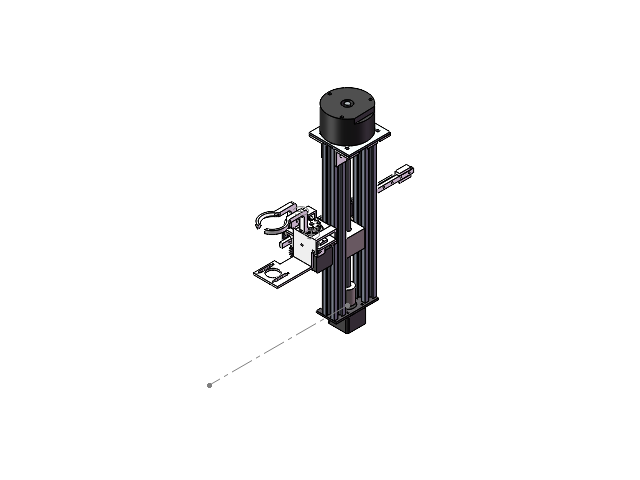
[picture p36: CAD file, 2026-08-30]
Mechanical Group/我说元神牛逼你说队/升降结构/杂/25物流车1.0-抓取机构-升降模块装配.SLDASM
25物流车1.0-抓取机构-电子-标准件-35闭环步进电机
25物流车1.0-抓取机构-标准件-刚性联轴器-5-8
25物流车1.0-抓取机构-标准件-丝杆-8-200
25物流车1.0-抓取机构-标准件-丝母-M8
25物流车1.0-抓取机构-标准件-丝母座-M8
25物流车1.0-抓取机构-标准件-滑轨-MGN9C x 2
25物流车1.0-抓取机构-标准件-滑块-MGN9C x 2
25物流车1.0-抓取机构-铝型材-2020-217 x 2
25物流车1.0-抓取机构-电子-标准件-g6220
25物流车1.0-抓取机构-碳板-3mm-升降35电机固定板
25物流车1.0-抓取机构-碳板-3mm-圆柱齿轮
25物流车1.0-抓取机构-碳板-3mm-水平轴连接板
25物流车1.0-抓取机构-电子-标准件-28闭环步进电机
25物流车1.0-抓取机构-标准件-法兰联轴器-5mm
25物流车1.0-抓取机构-cnc-yaw轴转接
25物流车1.0-抓取机构-铝型材-2020-2孔角件 x 4
25物流车1.0-抓取机构-标准件-滑轨-MGN7C
25物流车1.0-抓取机构-碳板-3mm-齿条3
25物流车1.0-标准件-电子-mg90
25物流车1.0-抓取机构-标准件-mg90舵盘
25物流车1.0-抓取机构-打印-舵机支架3
25物流车1.0-抓取机构-碳板-3mm-夹爪连板
25物流车1.0-抓取机构-标准件-板材连接件 x 3
25物流车1.0-抓取机构-打印-夹爪左
25物流车1.0-抓取机构-打印-夹爪右
25物流车1.0-抓取机构-标准件-轴套3-5-3.6 x 2
25物流车1.0-抓取机构-标准件-滑块-MGN7C x 2
25物流车测试底盘-打印-限位块

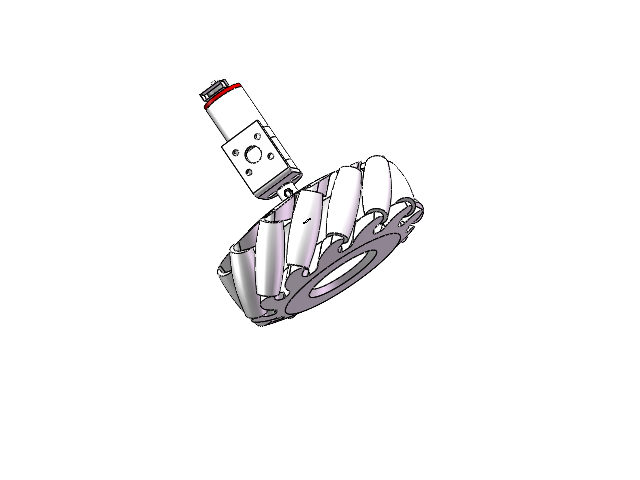
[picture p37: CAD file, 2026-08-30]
Mechanical Group/我说元神牛逼你说队/底盘/闭环左旋麦轮装配体.SLDASM
JGA25-371电机
电机固定
100mm麦克纳姆轮左旋轮
联轴器

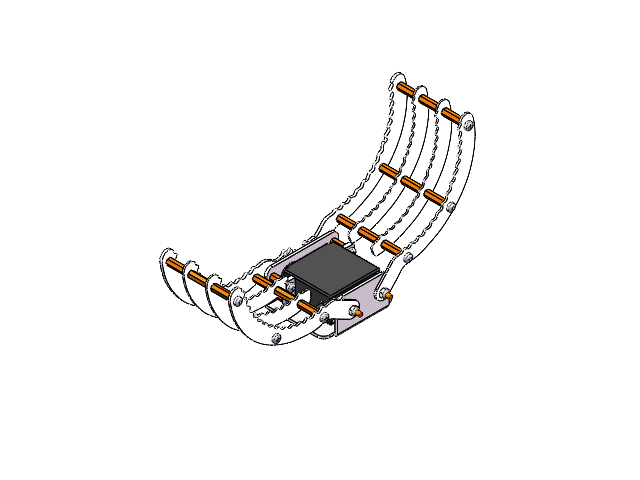
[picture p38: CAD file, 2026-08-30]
Mechanical Group/我说元神牛逼你说队/抓取/版本2/sw/黑金大爪子图纸.SLDASM
支架1
M3X11双通铜柱 x 4
GB818-M3X6-ZN-4.8 x 21
GB818-M3X10-ZN-4.8 x 2
底部长支架 x 2
GB6170-M3（自锁） x 3
短支架 x 4
M3X17+6铜柱 x 12
M3X16双通铜柱 x 6
GB818-M3X12-ZN-4.8
左边长支架
小舵机
金属主舵盘
右边长支架
GB818-M3X5-ZN-4.8 x 2

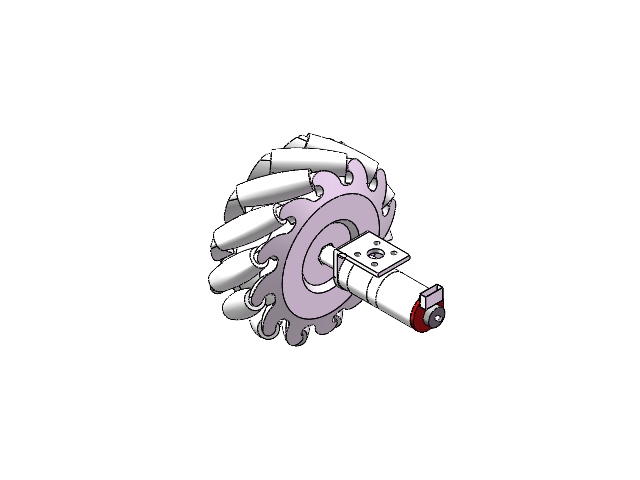
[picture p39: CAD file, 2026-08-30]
Mechanical Group/我说元神牛逼你说队/底盘/闭环右旋麦轮转配体.SLDASM
JGA25-371电机
电机固定
100mm麦克纳姆轮右旋轮
联轴器

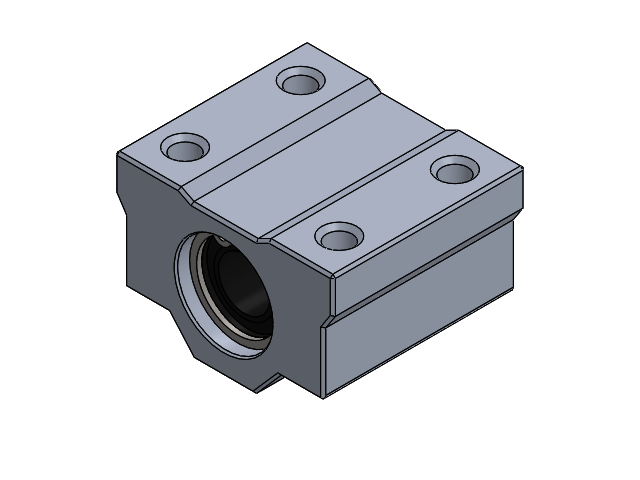
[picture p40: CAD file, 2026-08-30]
Mechanical Group/我说元神牛逼你说队/升降结构/SC8UU.SLDASM
SC8UU Block bearing
LM8UU
Freio x 2

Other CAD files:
Embedded Team/移植前/单个舵机驱动代码/89C51/01-舵机复位/Objects/main.obj
Embedded Team/移植前/单个舵机驱动代码/89C51/01-舵机控制/Objects/main.obj
Mechanical Group/我说元神牛逼你说队/抓取/版本2/sw/装配体4.SLDASM
Mechanical Group/我说元神牛逼你说队/升降结构/光轴装配体.SLDASM
Embedded Team/移植前/单个舵机驱动代码/89C51/01-舵机复位/Objects/Servo.obj
Embedded Team/移植前/单个舵机驱动代码/89C51/01-舵机控制/Objects/Servo.obj
Mechanical Group/26场地/26场地模型.SLDASM
Mechanical Group/26场地/26场地模型.STEP
Mechanical Group/26场地/场地.SLDPRT
Mechanical Group/26场地/核心框争夺判定圈.SLDPRT
Mechanical Group/26场地/球框.SLDPRT
Mechanical Group/26场地/球筐二维码.SLDPRT
Mechanical Group/26场地/皮球.SLDPRT
Mechanical Group/26场地/识别区.SLDPRT
Mechanical Group/我说元神牛逼你说队/临时/右轮.SLDPRT
Mechanical Group/我说元神牛逼你说队/临时/左轮1.SLDPRT
Mechanical Group/我说元神牛逼你说队/临时/底板上1.DWG
Mechanical Group/我说元神牛逼你说队/临时/底板上1.SLDDRW
Mechanical Group/我说元神牛逼你说队/临时/底板上1.SLDPRT
Mechanical Group/我说元神牛逼你说队/升降结构/42系列两相混合式步进电机[42HS04A]_42HS04A.SLDPRT
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

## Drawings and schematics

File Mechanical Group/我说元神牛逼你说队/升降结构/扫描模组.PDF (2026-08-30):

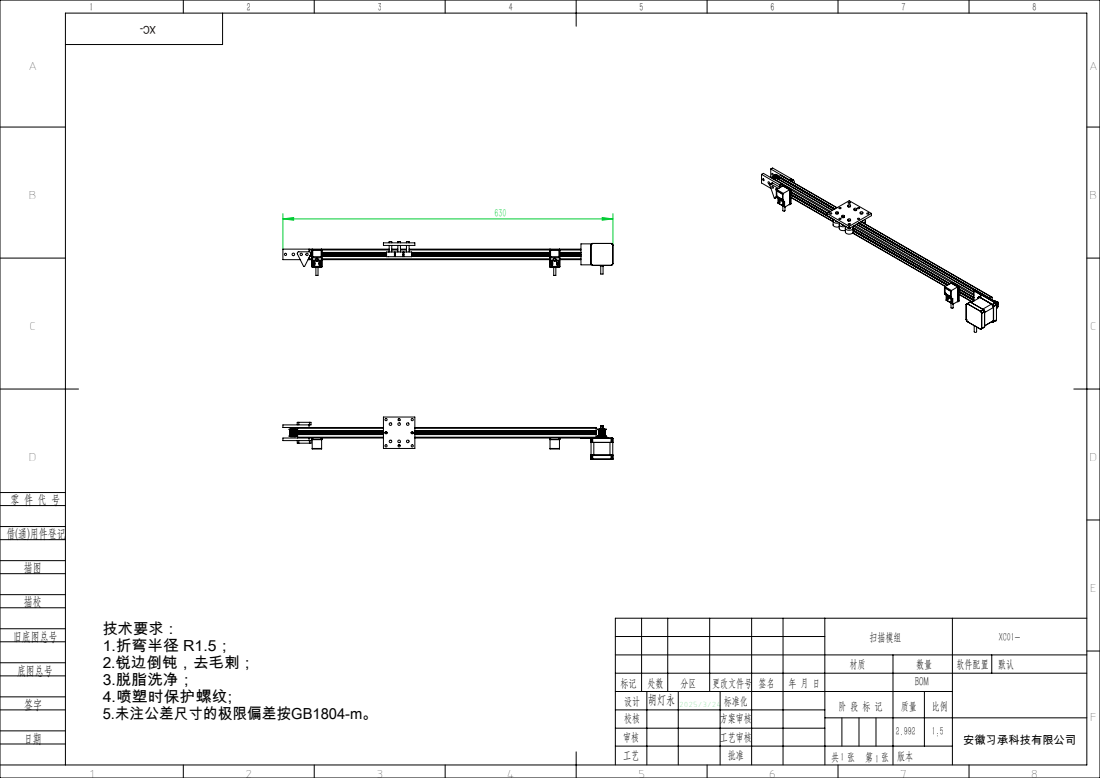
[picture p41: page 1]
1.折弯半径 R1.5；

扫描模组 | XC01-

材质 | 数量 | 软件配置 | 默认

标记 | 处数 | 分区 | 更改文件号 | 签名 | 年 月 日 | | BOM
设计 | 胡灯永 2025/3/24 | | 标准化 | | | 阶 段 标 记 | 质量 | 比例
校核 | | | 方案审核
审核 | | | 工艺审核
工艺 | | | 批准 | | | 共 张 第 张 1 1 | 版本

2.992 | 1:5 | 安徽习承科技有限公司

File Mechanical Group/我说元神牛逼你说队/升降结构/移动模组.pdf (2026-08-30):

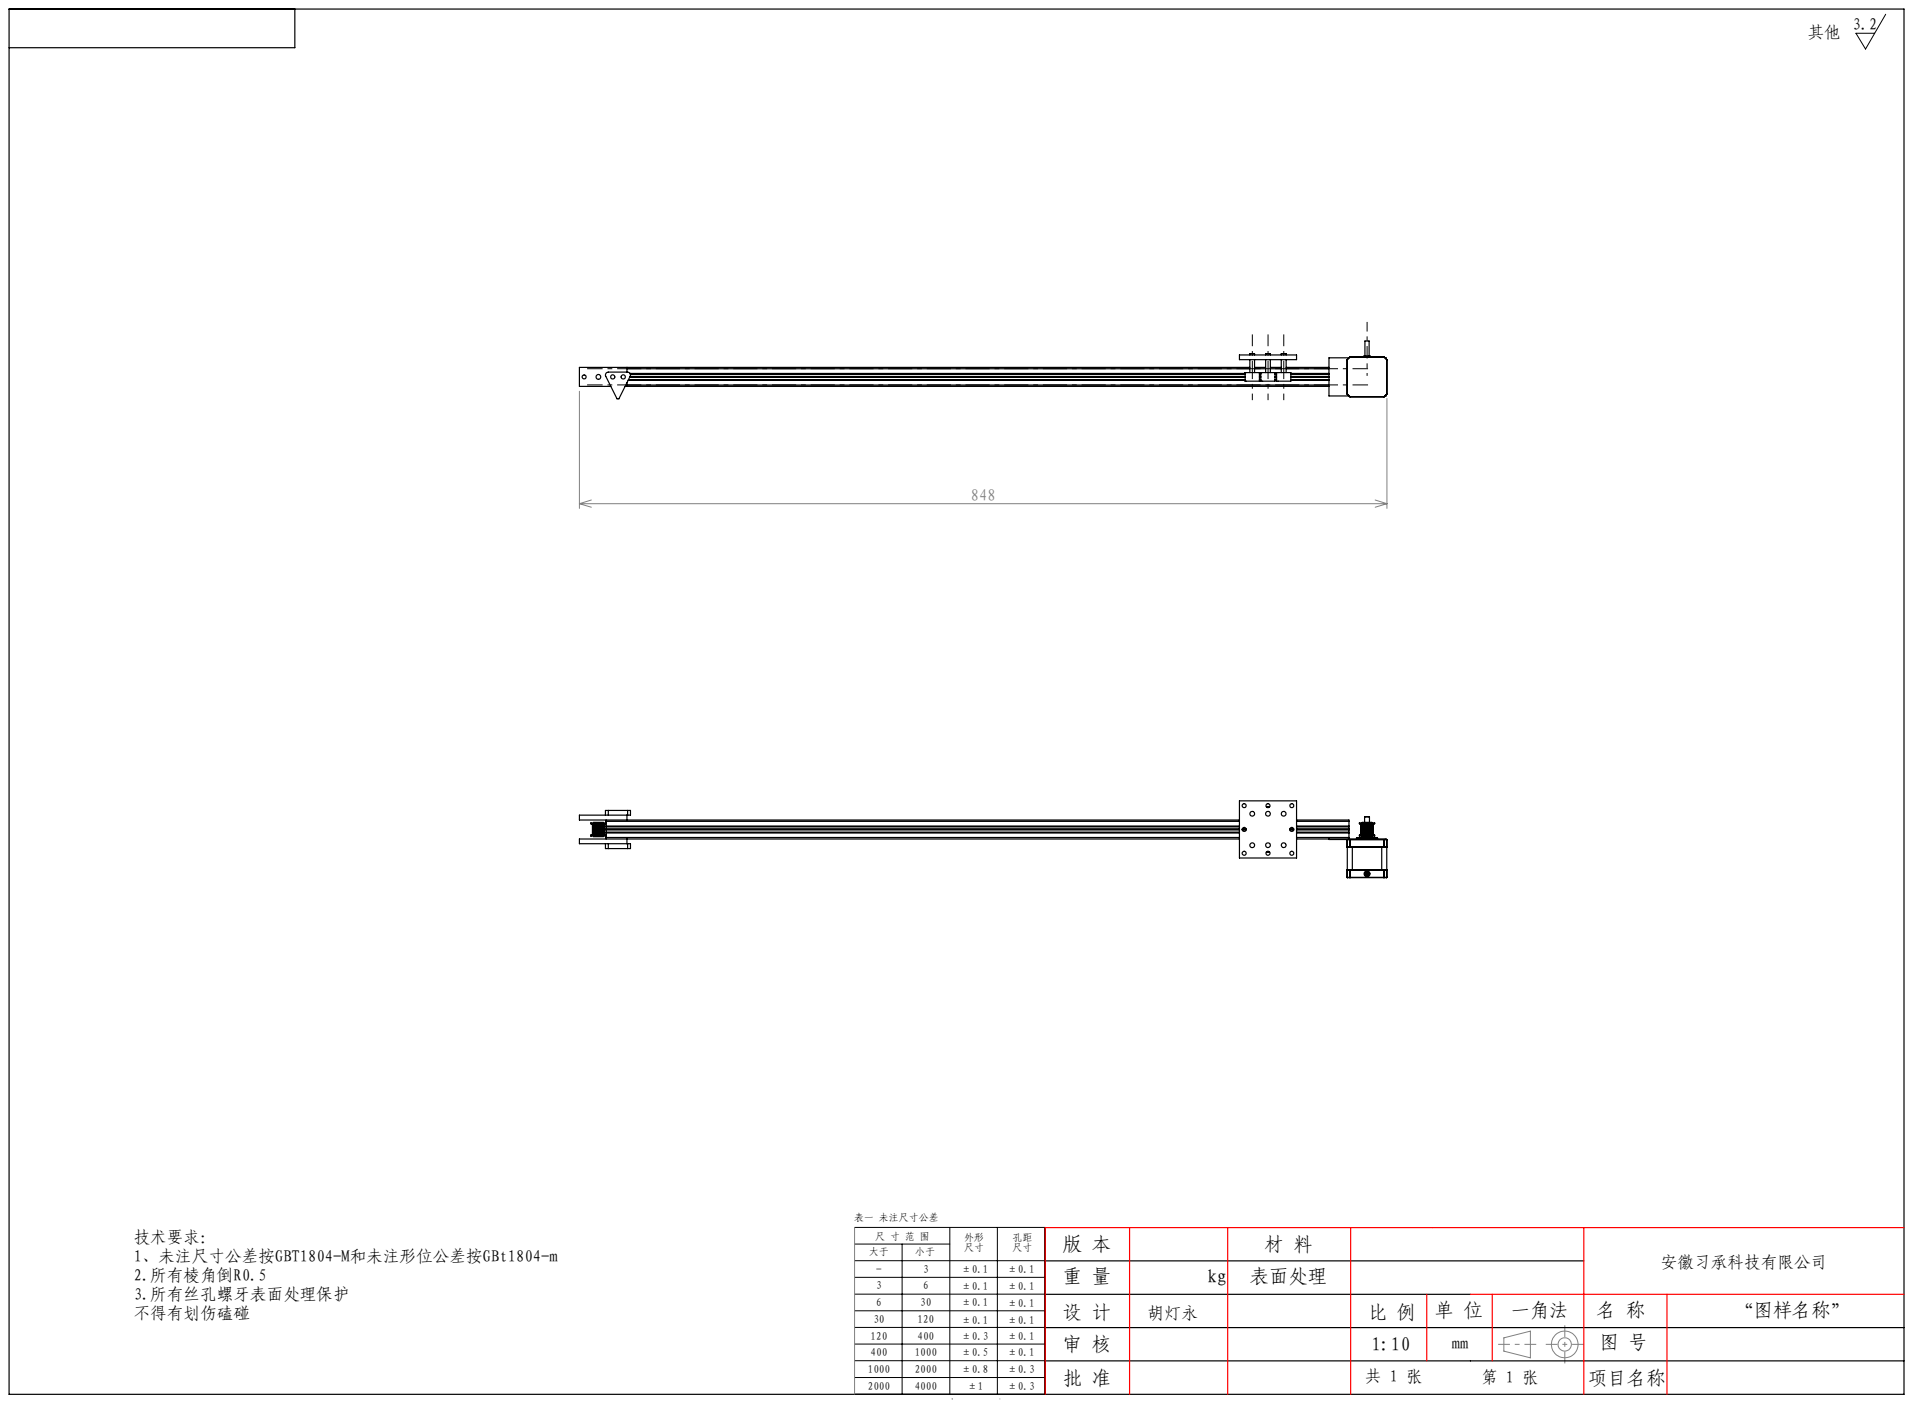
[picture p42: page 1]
表一 未注尺寸公差

孔距 尺寸 尺寸 ±0.1 ±0.1 ±1 ±0.3 | 版 本 | | 材 料 | | 安徽习承科技有限公司

重 量 | kg | 表面处理
设 计 | 胡灯永 | | 比 例 | 单 位 | 一角法 | 名 称 | “图样名称”
审 核 | | | 1:10 | mm | | | 图 号
批 准 | | | 共 1 张 第 1 张 | | | | 项目名称

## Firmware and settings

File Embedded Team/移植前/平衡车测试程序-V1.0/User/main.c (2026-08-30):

#include "stm32f10x.h"                  // Device header
#include "Delay.h"
#include "OLED.h"
#include "LED.h"
#include "Key.h"
#include "Motor.h"
#include "Encoder.h"
#include "MPU6050.h"
#include "Timer.h"
#include "PID.h"
#include "BlueSerial.h"
#include "Serial.h"
#include "NRF24L01.h"
#include "DebugMode.h"
#include "Store.h"
#include <math.h>
#include <stdio.h>

uint8_t RunFlag;

uint8_t RunFlagUpdate;

int16_t AX, AY, AZ, GX, GY, GZ;
int16_t AX_Offset, AZ_Offset, GY_Offset;
int16_t GY_Cali;

int8_t NRF_LV = 0;
int8_t NRF_RH = 0;

float AngleAcc;
float AngleAcc_Offset;
float AngleAcc_Cali;
float AngleAcc_Filter;
float AngleDelta;
float Angle;

float SpeedLeft, SpeedRight;
float AveSpeed, DifSpeed;

float AvePWM, DifPWM;
int16_t PWML, PWMR;

uint16_t SpeedLevel = 6; 

uint8_t DebugFlag;

#define ANGLE_T				10
#define SPEED_T				50

/*角度环PID参数*/
PID_t AnglePID = {	
	.Kp = 3,
	.Ki = 0.1,
	.Kd = 3,
	
	.OutMax = 100,
	.OutMin = -100,
	
	.OutOffset = 3,
};

/*速度环PID参数*/
PID_t SpeedPID = {	
	.Kp = 2,
	.Ki = 0.05,
	.Kd = 0,
	
	.OutMax = 10,
	.OutMin = -10,
};

/*转向环PID参数*/
PID_t TurnPID = {	
	.Kp = 2,
	.Ki = 1,
	.Kd = 0,
	
	.OutMax = 30,
	.OutMin = -30,
};

int main(void)
{
	/*初始化*/
	OLED_Init();
	LED_Init();
	Key_Init();
	Motor_Init();
	Encoder_Init();
	MPU6050_Init();
	BlueSerial_Init();
	Serial_Init();
	NRF24L01_Init();
	
	Timer_Init();
	
	/*显示初始界面*/
	OLED_Clear();
	OLED_ShowString(0, 0,  "  [GDELE提示]  ", OLED_8X16);
	OLED_ShowString(4, 16, " 平衡车测试程序 ", OLED_8X16);
	OLED_ShowString(0, 32, " 请注意执行校准 ", OLED_8X16);
	OLED_ShowString(0, 48, "             K4>", OLED_8X16);
	OLED_Update();
	
	/*按K4键继续*/
	while (Key_Check(KEY_4, KEY_SINGLE) == 0);
	Key_Clear();
	
	/*初始化FLASH并检查FLASH中有没有存储参数*/
	if (Store_Init())
	{
		/*未存储参数，将程序中的默认参数保存到FLASH中*/
		SaveParam();
		
		/*提示已重置参数*/
		OLED_Clear();
		OLED_ShowString(0, 0,  "     [提示]     ", OLED_8X16);
		OLED_ShowString(0, 16, "   已重置参数   ", OLED_8X16);
		OLED_ShowString(0, 32, " 请注意执行校准 ", OLED_8X16);
		OLED_ShowString(0, 48, "             K4>", OLED_8X16);
		OLED_Update();
		
		/*按K4键继续*/
		while (Key_Check(KEY_4, KEY_SINGLE) == 0);
		Key_Clear();
	}
	
	/*上电后加载FLASH中保存的参数*/
	LoadParam();
	
	OLED_Clear();
	BlueSerial_ClearBuffer();
	
	while (1)
	{
		/*指示灯*/
		if (RunFlag) {LED_ON();} else {LED_OFF();}
		
		/*按键*/
		if (Key_Check(KEY_1, KEY_SINGLE))		//K1按下，启动/停止
		{
			if (RunFlag == 0)
			{
				PID_Init(&AnglePID);
				PID_Init(&SpeedPID);
				PID_Init(&TurnPID);
				Angle = AngleAcc_Filter;
				RunFlag = 1;
			}
			else
			{
				RunFlag = 0;
			}
			BlueSerial_Printf("RunFlag=%d\r\n", RunFlag);
		}
		if (RunFlagUpdate)
		{
			RunFlagUpdate = 0;
			BlueSerial_Printf("RunFlag=%d\r\n", RunFlag);
		}
		if (Key_Check(KEY_2, KEY_SINGLE))		//K2按下，速度等级减1
		{
			if (SpeedLevel > 1) 
			{
				SpeedLevel --;
				SaveParam();
			}
			BlueSerial_Printf("SpeedLevel=%d\r\n", SpeedLevel);
		}
		if (Key_Check(KEY_3, KEY_SINGLE))		//K3按下，速度等级加1
		{
			if (SpeedLevel < 10)
			{
				SpeedLevel ++;
				SaveParam();
			}
			BlueSerial_Printf("SpeedLevel=%d\r\n", SpeedLevel);
		}
		if (Key_Check(KEY_4, KEY_SINGLE))		//K4按下，进入调试模式
		{
			DebugFlag = 1;
			RunFlag = 0;
			Motor_SetPWM(1, 0);
			Motor_SetPWM(2, 0);
			LED_OFF();
			Key_Clear();
			DebugMode();	//执行调试模式函数
		}
		
		/*蓝牙串口*/
		if (BlueSerial_ReceiveFlag())	//判断是否收到蓝牙数据包
		{
			BlueSerial_Receive();		//收到数据包，接收并解析数据包
			
			/*摇杆数据包，格式为：[joystick,LH,LV,RH,RV]*/
			if (strcmp(BlueSerial_StringArray[0], "joystick") == 0)
			{
				/*得到摇杆数据，转换为数值*/
				int8_t LH = atoi(BlueSerial_StringArray[1]);
				int8_t LV = atoi(BlueSerial_StringArray[2]);
				int8_t RH = atoi(BlueSerial_StringArray[3]);
				int8_t RV = atoi(BlueSerial_StringArray[4]);
				
				/*设定目标速度和目标转向幅度*/
				SpeedPID.Target = LV / 100.0 * SpeedLevel;
				TurnPID.Target = RH / 100.0 * SpeedLevel;
			}
			/*按键数据包，格式为：[key,按键名称,down/up]*/
			else if (strcmp(BlueSerial_StringArray[0], "key") == 0)
			{
				if (strcmp(BlueSerial_StringArray[1], "1") == 0 
				 && strcmp(BlueSerial_StringArray[2], "up") == 0)		//收到数据包[key,1,up]
				{
					Key_Flag[KEY_1] |= KEY_SINGLE;		//触发平衡车K1键按下
				}
				else if (strcmp(BlueSerial_StringArray[1], "2") == 0 
					  && strcmp(BlueSerial_StringArray[2], "up") == 0)	//收到数据包[key,2,up]
				{
					Key_Flag[KEY_2] |= KEY_SINGLE;		//触发平衡车K2键按下
				}
				else if (strcmp(BlueSerial_StringArray[1], "3") == 0 
					  && strcmp(BlueSerial_StringArray[2], "up") == 0)	//收到数据包[key,3,up]
				{
					Key_Flag[KEY_3] |= KEY_SINGLE;		//触发平衡车K3键按下
				}
			}
		}
		
		/*无线模块*/
		if (NRF24L01_Receive() == 1)	//判断是否收到无线模块数据包
		{
			
			if (NRF24L01_RxPacket[0] == 1)		//字节0为1，表示需要返回状态信息
			{
				/*写入相关的状态信息*/
				NRF24L01_TxPacket[0] = 0x00;					//0
				NRF24L01_TxPacket[1] = SpeedLevel;				//1
				NRF24L01_TxPacket[2] = PWML;					//2
				NRF24L01_TxPacket[3] = PWMR;					//3
				*(float *)&NRF24L01_TxPacket[4] = Angle;		//4 5 6 7
				*(float *)&NRF24L01_TxPacket[8] = SpeedLeft;	//8 9 10 11
				*(float *)&NRF24L01_TxPacket[12] = SpeedRight;	//12 13 14 15
				
				/*发送状态信息给遥控器，以便在遥控器上观察平衡车状态*/
				NRF24L01_Send();
			}
			
			/*得到遥控器数据*/
			int8_t LV = NRF24L01_RxPacket[2];
			int8_t RH = NRF24L01_RxPacket[3];
			uint8_t KEY0 = NRF24L01_RxPacket[5];
			NRF_LV = LV;
			NRF_RH = RH;
			
			/*设定目标速度和目标转向幅度*/
			SpeedPID.Target = LV / 100.0 * SpeedLevel;
			TurnPID.Target = RH / 100.0 * SpeedLevel;
			
			/*处理遥控器按键事件*/
			if (KEY0 & 0x01)					//遥控器K1键按下
			{
				Key_Flag[KEY_3] |= KEY_SINGLE;	//触发平衡车K3键按下
			}
			if (KEY0 & 0x02)					//遥控器K2键按下
			{
				Key_Flag[KEY_2] |= KEY_SINGLE;	//触发平衡车K2键按下
			}
			if (KEY0 & 0x04)					//遥控器K3键按下
			{
				Key_Flag[KEY_1] |= KEY_SINGLE;	//触发平衡车K1键按下
			}
			
		}
		
		/*OLED显示*/
		OLED_Printf(0, 0, OLED_6X8, "Angle  Speed  Turn");
		OLED_Printf(0, 10, OLED_6X8, "%+06.1f %+06.1f %+06.1f", AnglePID.Target, SpeedPID.Target, TurnPID.Target);
		OLED_Printf(0, 18, OLED_6X8, "%+06.1f %+06.1f %+06.1f", Angle, AveSpeed, DifSpeed);
		OLED_Printf(0, 26, OLED_6X8, "%+06.1f %+06.1f %+06.1f", AnglePID.Out, SpeedPID.Out, TurnPID.Out);
		
		OLED_DrawLine(0, 36, 127, 36);
		
		OLED_Printf(0, 40, OLED_6X8, "PWML:%+05d PWMR:%+05d", PWML, PWMR);
		OLED_Printf(0, 48, OLED_6X8, "SpdL:%+05.1f SpdR:%+05.1f", SpeedLeft, SpeedRight);
		OLED_Printf(0, 56, OLED_6X8, "SpdLevel:%1d", SpeedLevel);
		OLED_Update();
	}
}

void TIM1_UP_IRQHandler(void)
{
	static uint16_t SensorCount0, SensorCount1;
	static uint16_t RunCount0, RunCount1;
	
	if (TIM_GetITStatus(TIM1, TIM_IT_Update) == SET)
	{
		TIM_ClearITPendingBit(TIM1, TIM_IT_Update);
		
		/*定时器定时中断，每隔1ms自动执行一次*/
		
		/*驱动非阻塞式按键*/
		Key_Tick();
		
		/*进入调试模式后，不执行后续PID程序，以免干扰调试*/
		if (DebugFlag) {return;}
		
		SensorCount0 ++;
		if (SensorCount0 >= ANGLE_T)		//每隔ANGLE_T定义的时间执行一次
		{
			SensorCount0 = 0;
			
			/*姿态解析，得到平衡车角度*/
			
			/*获取陀螺仪加速度计原始数据*/
			MPU6050_GetData(&AX, &AY, &AZ, &GX, &GY, &GZ);
			
			/*陀螺仪数据校准*/
			GY_Cali = GY + GY_Offset;
			
			/*计算加速度计角度*/
			AngleAcc = -atan2(AX, AZ) / 3.1415926535 * 180;
			
			/*计算陀螺仪角度增量*/
			AngleDelta = GY_Cali / 32768.0 * 2000.0 * (ANGLE_T / 1000.0);
			
			/*中心角度校准*/
			AngleAcc_Cali = AngleAcc + AngleAcc_Offset;
			
			/*对加速度计角度进行一阶低通滤波，使其更平滑*/
			float Alpha0 = 0.8;
			AngleAcc_Filter = Alpha0 * AngleAcc_Filter + (1 - Alpha0) * AngleAcc_Cali;
			
			/*角度累加陀螺仪角度增量，得到新的角度值*/
			Angle += AngleDelta;
			
			/*新的角度值与加速度计角度进行互补滤波，抑制漂移*/
			float Alpha1 = fabs(DifSpeed) / 5.0 * 0.02 + 0.005;		//根据差速动态调整滤波参数
			if (Alpha1 > 0.02) {Alpha1 = 0.02;}						//参数限幅
			Angle = Alpha1 * AngleAcc_Filter + (1 - Alpha1) * Angle;//互补滤波得到角度值
			
			/*平衡车倒地后，自动停止*/
			if (Angle > 50 || Angle < -50)
			{
				if (RunFlag)
				{
					RunFlag = 0;
					RunFlagUpdate = 1;
				}
			}
		}
		
		SensorCount1 ++;
		if (SensorCount1 >= SPEED_T)		//每隔SPEED_T定义的时间执行一次
		{
			SensorCount1 = 0;
			
			/*通过编码器获取电机旋转速度*/
			SpeedLeft = Encoder_Get(1) / 408.0 / (SPEED_T / 1000.0);
			SpeedRight = Encoder_Get(2) / 408.0 / (SPEED_T / 1000.0);
			
			/*获取均速和差速*/
			AveSpeed = (SpeedLeft + SpeedRight) / 2.0;
			DifSpeed = SpeedLeft - SpeedRight;
		}
		
		/*PID控制*/
		if (RunFlag)
		{
			RunCount0 ++;
			if (RunCount0 >= ANGLE_T)		//每隔ANGLE_T定义的时间执行一次
			{
				RunCount0 = 0;
				
				/*角度环PID计算*/
				AnglePID.Actual = Angle;
				PID_Update(&AnglePID);
				AvePWM = -AnglePID.Out;		//角度环输出作用于平均PWM
				
				/*平均PWM和差分PWM，合成左轮PWM和右轮PWM*/
				PWML = AvePWM + DifPWM;
				PWMR = AvePWM - DifPWM;
				
				/*PWM限幅*/
				if (PWML > 100) {PWML = 100;} else if (PWML < - 100) {PWML = -100;}
				if (PWMR > 100) {PWMR = 100;} else if (PWMR < - 100) {PWMR = -100;}
				
				/*PWM输出至电机*/
				Motor_SetPWM(1, PWML);
				Motor_SetPWM(2, PWMR);
			}
			
			RunCount1 ++;
			if (RunCount1 >= SPEED_T)		//每隔SPEED_T定义的时间执行一次
			{
				RunCount1 = 0;
				
				/*速度环PID计算*/
				SpeedPID.Actual = AveSpeed;
				PID_Update(&SpeedPID);
				AnglePID.Target = SpeedPID.Out;	//速度环输出作用于角度环输入
				
				/*转向环PID计算*/
				TurnPID.Actual = DifSpeed;
				PID_Update(&TurnPID);
				DifPWM = TurnPID.Out;		//转向环输出作用于差分PWM
			}
		}
		else
		{
			Motor_SetPWM(1, 0);				//RunFlag为0时，电机停止
			Motor_SetPWM(2, 0);
		}
	}
}

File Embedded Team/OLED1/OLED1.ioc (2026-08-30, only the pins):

Mcu.UserName=STM32F407VETx
PA0-WKUP.Signal=GPIO_Input
PA13.Signal=SYS_JTMS-SWDIO
PA14.Signal=SYS_JTCK-SWCLK
PB2.Signal=GPIO_Output
PC14-OSC32_IN.Signal=RCC_OSC32_IN
PC15-OSC32_OUT.Signal=RCC_OSC32_OUT
PH0-OSC_IN.Signal=RCC_OSC_IN
PH1-OSC_OUT.Signal=RCC_OSC_OUT

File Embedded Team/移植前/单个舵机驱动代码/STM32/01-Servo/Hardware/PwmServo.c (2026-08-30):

// ========================= 头文件 =========================
#include "PwmServo.h"   // 本文件对应的头文件，包含宏、类型定义等
#include "Global.h"     // 全局变量/宏定义
#include <math.h>
// ========================= 全局变量 =========================
servo_t duoji_doing[DJ_NUM];   // 保存 0~7 号舵机的“运行中”参数（目标值、当前值、增量、执行时间、偏差等）

// ========================= 函数实现 =========================

/*----------------------------------------------------------
 * 函数名称：PwmServoInit
 * 功    能：舵机 GPIO 初始化（推挽输出 50 MHz）
 * 参    数：无
 * 返 回 值：无
 *----------------------------------------------------------*/
void PwmServoInit(void)
{
    u8 i;
    GPIO_InitTypeDef GPIO_InitStructure;

    // 1. 使能所用端口的 RCC 时钟
    RCC_APB2PeriphClockCmd(SERVO0_GPIO_CLK | SERVO1_GPIO_CLK | SERVO2_GPIO_CLK |
                           SERVO3_GPIO_CLK | SERVO4_GPIO_CLK | SERVO5_GPIO_CLK |
                           SERVO6_GPIO_CLK, ENABLE);

    // 2. 统一结构体参数：50 MHz 推挽输出
    GPIO_InitStructure.GPIO_Speed = GPIO_Speed_50MHz;
    GPIO_InitStructure.GPIO_Mode  = GPIO_Mode_Out_PP;

    // 3. 依次初始化 7 路 GPIO（宏在头文件定义）
    GPIO_InitStructure.GPIO_Pin = SERVO0_PIN;  GPIO_Init(SERVO0_GPIO_PORT, &GPIO_InitStructure);
    GPIO_InitStructure.GPIO_Pin = SERVO1_PIN;  GPIO_Init(SERVO1_GPIO_PORT, &GPIO_InitStructure);
    GPIO_InitStructure.GPIO_Pin = SERVO2_PIN;  GPIO_Init(SERVO2_GPIO_PORT, &GPIO_InitStructure);
    GPIO_InitStructure.GPIO_Pin = SERVO3_PIN;  GPIO_Init(SERVO3_GPIO_PORT, &GPIO_InitStructure);
    GPIO_InitStructure.GPIO_Pin = SERVO4_PIN;  GPIO_Init(SERVO4_GPIO_PORT, &GPIO_InitStructure);
    GPIO_InitStructure.GPIO_Pin = SERVO5_PIN;  GPIO_Init(SERVO5_GPIO_PORT, &GPIO_InitStructure);
    GPIO_InitStructure.GPIO_Pin = SERVO6_PIN;  GPIO_Init(SERVO6_GPIO_PORT, &GPIO_InitStructure);

    // 4. 初始化全局结构体数组：默认目标 1500us，当前 1500us，增量 20，时间 5000ms
    for (i = 0; i < DJ_NUM; i++)
    {
        duoji_doing[i].aim  = 1500;
        duoji_doing[i].cur  = 1500;
        duoji_doing[i].inc  = 20;
        duoji_doing[i].time = 5000;
    }
}

/*----------------------------------------------------------
 * 函数名称：PwmServo_PinSet
 * 功    能：直接设置某个舵机引脚电平（用于软件 PWM）
 * 参    数：index 0~7   level 1=高 0=低
 * 返 回 值：无
 *----------------------------------------------------------*/
void PwmServo_PinSet(u8 index, BitAction level)
{
    switch (index)
    {
        case 0: SERVO0_PIN_SET(level); break;
        case 1: SERVO1_PIN_SET(level); break;
        case 2: SERVO2_PIN_SET(level); break;
        case 3: SERVO3_PIN_SET(level); break;
        case 4: SERVO4_PIN_SET(level); break;
        case 5: SERVO5_PIN_SET(level); break;
        case 6: SERVO6_PIN_SET(level); break;
//        case 7: SERVO7_PIN_SET(level); break;
        default: break;
    }
}

/*----------------------------------------------------------
 * 函数名称：PwmServo_DoingSet
 * 功    能：给指定舵机下发“平滑运动”指令
 * 参    数：index 0~6
 *            aim   目标脉宽 500~2500 us（0 表示停止）
 *            time  完成动作所需时间 0~10000 ms
 * 返 回 值：无
 * 注    意：内部会计算每 20 ms 需要增加/减少的增量 inc
 *----------------------------------------------------------*/
void PwmServo_DoingSet(u8 index, int aim, int time)
{
    if (index >= DJ_NUM) return;          // 越界保护

    /* 1. aim==0 视为停止 */
    if (aim == 0)
    {
        duoji_doing[index].inc = 0;       // 不再递增
        duoji_doing[index].aim = duoji_doing[index].cur;
        return;
    }

    /* 2. 限幅 */
    if (aim > 2490) aim = 2490;
    else if (aim < 510) aim = 510;

    if (time > 10000) time = 9999;

    /* 3. 若当前值已等于目标值，为防止除 0，人为增加微小偏移（0.0077） */
    if (duoji_doing[index].cur == aim)
    {
        aim += 0.0077f;
    }

    /* 4. 时间太短（<20ms）→ 立即到位 */
    if (time < 20)
    {
        duoji_doing[index].aim = aim;
        duoji_doing[index].cur = aim;
        duoji_doing[index].inc = 0;
        // printf("#%03dP%04dT%04d!", (u16)index, (u16)aim, 0);
    }
    /* 5. 正常平滑运动：计算 20 ms 一次增量 inc */
    else
    {
        duoji_doing[index].aim  = aim;
        duoji_doing[index].time = time;
        duoji_doing[index].inc  = (aim - duoji_doing[index].cur) / (time / 20.0f);
        // printf("#%03dP%04dT%04d!", (u16)index, (u16)aim, (u16)time);
    }
}

/*----------------------------------------------------------
 * 函数名称：PwmServo_IncOffset
 * 功    能：在 20 ms 周期任务里调用，让舵机“走一步”
 * 参    数：index 0~7
 * 返 回 值：无
 *----------------------------------------------------------*/
void PwmServo_IncOffset(u8 index)
{
    int aim_temp;

    if (duoji_doing[index].inc == 0) return; // 无需移动

    aim_temp = duoji_doing[index].aim;

    /* 1. 再次限幅（冗余保护） */
    if (aim_temp > 2490) aim_temp = 2490;
    else if (aim_temp < 500) aim_temp = 500;

    /* 2. 判断是否到达目标，若到达则停止 */
    if (abs_float(aim_temp - duoji_doing[index].cur) <= abs_float(duoji_doing[index].inc * 2))
    {
        duoji_doing[index].cur = aim_temp;
        duoji_doing[index].inc = 0;
    }
    /* 3. 未到达，累加增量 */
    else
    {
        duoji_doing[index].cur += duoji_doing[index].inc;
    }
}

/*----------------------------------------------------------
 * 函数名称：PwmServo_BiasSet
 * 功    能：单独给某舵机设置“偏差”参数（用于校准舵机中位）
 * 参    数：index 0~7   bias 偏差值
 * 返 回 值：无
 *----------------------------------------------------------*/
void PwmServo_BiasSet(uint8_t index, int bias)
{
    if (index >= DJ_NUM) return;
    duoji_doing[index].bias = bias;
    duoji_doing[index].inc  = 0.001f; // 给一个极小增量，防止除 0
}

/*----------------------------------------------------------
 * 函数名称：PwmServoStop
 * 功    能：停止指定舵机或全部舵机
 * 参    数：index 0~7 指定舵机；255 表示全部
 * 返 回 值：无
 *----------------------------------------------------------*/
void PwmServoStop(u8 index)
{
    if (index < DJ_NUM) // 单路停止
    {
        duoji_doing[index].inc = 0;
        duoji_doing[index].aim = duoji_doing[index].cur;
    }
    else if (index == 255) // 全部停止
    {
        for (index = 0; index < DJ_NUM; index++)
        {
            duoji_doing[index].inc = 0;
            duoji_doing[index].aim = duoji_doing[index].cur;
        }
    }
}

float fix_raio = 0.99;
/**********************************************************
 * @brief 设置舵机角度
 * @param angle: float -> [0, 180]
 **********************************************************/
void PwmServo_SetAngle(uint8_t index, float angle,float Servo_angle){ 
    angle = fmax(0, fmin(angle, Servo_angle));

    angle *= fix_raio;

    float duty = 500 + (angle/Servo_angle)*2000;
    
    PwmServo_DoingSet(index, duty, 1000);
}

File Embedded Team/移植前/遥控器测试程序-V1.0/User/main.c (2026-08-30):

//#include "stm32f10x.h"                  // Device header
//#include "Delay.h"
//#include "OLED.h"
//#include "Key.h"
//#include "AD.h"
//#include "NRF24L01.h"
//#include "Timer.h"

//uint16_t AD_LH, AD_LV, AD_RH, AD_RV;
//int8_t LH, LV, RH, RV;

//uint8_t KEY0, KEY1;
//uint8_t KeyNum;

//uint8_t SendFlag;
//uint8_t SuccessRatio;

//uint8_t Flag;

//uint8_t Mode = 0;

//#define AD_DEAD			100

//int8_t DataProcess(uint16_t ADValue);
//uint8_t CalculateSuccessRatio(uint8_t SendFlag);

//int main(void)
//{
//	/*初始化*/
//	OLED_Init();
//	Key_Init();
//	AD_Init();
//	NRF24L01_Init();
//	Timer_Init();
//	
//	/*显示初始界面*/
//	OLED_Clear();
//	OLED_ShowString(0, 0,  "     [GDELE]   ", OLED_8X16);
//	OLED_ShowString(4, 16, " 遥控器测试程序 ", OLED_8X16);
//	OLED_ShowString(0, 32, "      V1.0      ", OLED_8X16);
//	OLED_ShowString(0, 48, "            K10>", OLED_8X16);
//	OLED_Update();
//	
//	/*按K10键继续*/
//	while (Key_Check(KEY_10, KEY_SINGLE) == 0);
//	Key_Clear();

//	OLED_Clear();
//	
//	while (1)
//	{
//		KeyNum = 0;
//		
//		/*读取左右摇杆的AD值*/
//		AD_LH = AD_GetValue(ADC_Channel_0);
//		AD_LV = AD_GetValue(ADC_Channel_1);
//		AD_RH = AD_GetValue(ADC_Channel_2);
//		AD_RV = AD_GetValue(ADC_Channel_3);
//		
//		/*对AD值进行数据处理，得到摇杆数据*/
//		LH = DataProcess(AD_LH);
//		LV = DataProcess(AD_LV);
//		RH = DataProcess(AD_RH);
//		RV = DataProcess(AD_RV);
//		
//		/*读取按键*/
//		if (Key_Check(KEY_1, KEY_SINGLE))
//		{
//			KEY0 |= 0x01;
//			KeyNum = 1;
//		}
//		if (Key_Check(KEY_2, KEY_SINGLE))
//		{
//			KEY0 |= 0x02;
//			KeyNum = 2;
//		}
//		if (Key_Check(KEY_3, KEY_SINGLE))
//		{
//			KEY0 |= 0x04;
//			KeyNum = 3;
//		}
//		if (Key_Check(KEY_4, KEY_SINGLE))
//		{
//			KEY0 |= 0x08;
//			KeyNum = 4;
//		}
//		if (Key_Check(KEY_5, KEY_SINGLE))
//		{
//			KEY0 |= 0x10;
//			KeyNum = 5;
//		}
//		if (Key_Check(KEY_6, KEY_SINGLE))
//		{
//			KEY0 |= 0x20;
//			KeyNum = 6;
//		}
//		if (Key_Check(KEY_7, KEY_SINGLE))
//		{
//			KEY0 |= 0x40;
//			KeyNum = 7;
//		}
//		if (Key_Check(KEY_8, KEY_SINGLE))
//		{
//			KEY0 |= 0x80;
//			KeyNum = 8;
//		}
//		if (Key_Check(KEY_9, KEY_SINGLE))
//		{
//			KEY1 |= 0x01;
//			KeyNum = 9;
//		}
//		if (Key_Check(KEY_10, KEY_SINGLE))
//		{
//			KEY1 |= 0x02;
//			KeyNum = 10;
//		}
//		if (Key_Check(KEY_11, KEY_SINGLE))
//		{
//			KEY1 |= 0x04;
//			KeyNum = 11;
//		}
//		if (Key_Check(KEY_12, KEY_SINGLE))
//		{
//			KEY1 |= 0x08;
//			KeyNum = 12;
//		}
//		
//		/*定时器中，每隔100ms，置一次Flag*/
//		/*即每隔100ms，发送一次数据*/
//		if (Flag)
//		{
//			Flag = 0;
//			
//			/*填充遥控器数据*/
//			NRF24L01_TxPacket[0] = Mode;
//			NRF24L01_TxPacket[1] = LH;
//			NRF24L01_TxPacket[2] = LV;
//			NRF24L01_TxPacket[3] = RH;
//			NRF24L01_TxPacket[4] = RV;
//			NRF24L01_TxPacket[5] = KEY0;
//			NRF24L01_TxPacket[6] = KEY1;
//			
//			/*发送遥控器数据*/
//			SendFlag = NRF24L01_Send();
//			
//			/*发送成功后，清除按键，确保按键被成功发出*/
//			if (SendFlag == 1)
//			{
//				KEY0 = 0;
//				KEY1 = 0;
//			}
//			
//			/*计算发送成功率，用于显示信号值*/
//			SuccessRatio = CalculateSuccessRatio(SendFlag);
//		}
//		
//		/*按键按下，在屏幕右上角闪烁此按键值*/
//		if (KeyNum)
//		{
//			OLED_Printf(104, 0, OLED_8X16, "K%d", KeyNum);
//			OLED_UpdateArea(104, 0, 24, 16);
//			Delay_ms(100);
//			OLED_ClearArea(104, 0, 24, 16);
//			OLED_UpdateArea(104, 0, 24, 16);
//		}
//		
//		/*K9键按下，切换显示模式*/
//		if (KeyNum == 9)
//		{
//			Mode = !Mode;
//			OLED_Clear();
//		}
//		
//		/*模式0时，屏幕显示摇杆数据*/
//		if (Mode == 0)
//		{
//			OLED_Printf(0, 16, OLED_8X16, "LH:%+04d", LH);
//			OLED_Printf(0, 32, OLED_8X16, "LV:%+04d", LV);
//			OLED_Printf(72, 16, OLED_8X16, "RH:%+04d", RH);
//			OLED_Printf(72, 32, OLED_8X16, "RV:%+04d", RV);
//		}
//		/*模式1时，屏幕显示平衡车返回的状态信息*/
//		else if (Mode == 1)
//		{
//			if (NRF24L01_Receive() == 1)
//			{
//				uint8_t SpeedLevel = NRF24L01_RxPacket[1];
//				int8_t PWML = NRF24L01_RxPacket[2];
//				int8_t PWMR = NRF24L01_RxPacket[3];
//				float Angle = *(float *)&NRF24L01_RxPacket[4];
//				float SpeedLeft = *(float *)&NRF24L01_RxPacket[8];
//				float SpeedRight = *(float *)&NRF24L01_RxPacket[12];
//				
//				OLED_Clear();
//				OLED_Printf(0, 21, OLED_6X8, "Angle:%+06.1f", Angle);
//				OLED_DrawLine(0, 36, 127, 36);
//				OLED_Printf(0, 40, OLED_6X8, "PWML:%+05d PWMR:%+05d", PWML, PWMR);
//				OLED_Printf(0, 48, OLED_6X8, "SpdL:%+05.1f SpdR:%+05.1f", SpeedLeft, SpeedRight);
//				OLED_Printf(0, 56, OLED_6X8, "SpdLevel:%1d", SpeedLevel);
//				
//			}
//		}
//		
//		/*根据发送成功率，在屏幕左上角显示对应的信号值*/
//		if (SuccessRatio >= 9)
//		{
//			OLED_ShowImage(0, 0, 16, 16, Signal_3);
//		}
//		else if (SuccessRatio >= 5)
//		{
//			OLED_ShowImage(0, 0, 16, 16, Signal_2);
//		}
//		else if (SuccessRatio >= 1)
//		{
//			OLED_ShowImage(0, 0, 16, 16, Signal_1);
//		}
//		else
//		{
//			OLED_ShowImage(0, 0, 16, 16, Signal_0);
//		}
//		
//		OLED_Update();
//	}
//}

//int8_t DataProcess(uint16_t ADValue)		//摇杆AD数据处理函数
//{
//	/*输入ADValue，范围：0 ~ 4095*/
//	int32_t Value;;
//	
//	/*减去中心AD值，范围：-2048 ~ 2047*/
//	Value = ADValue - 2048;
//	
//	/*摇杆回中时，设定一个死区区间，确保回中时摇杆值为0*/
//	/*调整后，范围：-(2048-AD_DEAD) ~ 2047-AD_DEAD*/
//	if (Value > AD_DEAD)
//	{
//		Value -= AD_DEAD;
//	}
//	else if (Value < -AD_DEAD)
//	{
//		Value += AD_DEAD;
//	}
//	else
//	{
//		Value = 0;
//	}
//	
//	/*对值进行缩放，得到最终摇杆数据*/
//	/*缩放后，范围：-100 ~ 100*/
//	Value = Value * 101 / (2049 - AD_DEAD);
//	
//	return Value;
//}

//uint8_t CalculateSuccessRatio(uint8_t SendFlag)		//计算发送成功率
//{
//	static uint8_t SendFlagArray[10];
//	static uint8_t p;
//	uint8_t i, SuccessCount;
//	
//	/*取最近10次的SendFlag，统计发送成功的次数*/
//	SendFlagArray[p] = SendFlag;
//	p ++;
//	p %= 10;
//	
//	SuccessCount = 0;
//	for (i = 0; i < 10; i ++)
//	{
//		if (SendFlagArray[i] == 1)
//		{
//			SuccessCount ++;
//		}
//	}
//	
//	/*返回最近10次发送成功的次数*/
//	return SuccessCount;
//}

//void TIM1_UP_IRQHandler(void)
//{
//	static uint16_t Count;
//	if (TIM_GetITStatus(TIM1, TIM_IT_Update) == SET)
//	{
//		/*定时器定时中断，每隔1ms自动执行一次*/
//		
//		/*驱动非阻塞式按键*/
//		Key_Tick();
//		
//		Count ++;
//		if (Count >= 1)
//		{
//			Count = 0;
//			
//			Flag = 1;		//100ms置一次Flag
//		}
//		TIM_ClearITPendingBit(TIM1, TIM_IT_Update);
//	}
//}
/* 通过 NRF24L01 将解析结果发送回遥控器 */
#include "stm32f10x.h"                  // Device header
#include "Delay.h"
#include "OLED.h"
#include "Key.h"
#include "AD.h"
#include "NRF24L01.h"
#include "Timer.h"
#include <string.h>

uint16_t AD_LH, AD_LV, AD_RH, AD_RV;
int8_t LH, LV, RH, RV;

uint8_t KEY0, KEY1;
uint8_t KeyNum;

uint8_t SendFlag;
uint8_t SuccessRatio;

uint8_t Flag;

uint8_t Mode = 0;

/* ========== 车端回传的 QR 解析结果 ========== */
static char QR_base[16]   = {0};
static char QR_core[16]   = {0};
static char QR_left[16]   = {0};
static char QR_middle[16] = {0};
static char QR_right[16]  = {0};

#define AD_DEAD			100

int8_t DataProcess(uint16_t ADValue);
uint8_t CalculateSuccessRatio(uint8_t SendFlag);
void     ParseQRData(char *str);
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
